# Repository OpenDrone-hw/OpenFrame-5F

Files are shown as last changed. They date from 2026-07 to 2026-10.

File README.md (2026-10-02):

# OpenFrame-5F

The 5" OpenFrame: a CNC carbon fibre freestyle FPV frame in the
incutec OpenDrone line. The 3" and 5" frames are separate repositories:
[OpenFrame-3F](https://github.com/OpenDrone-hw/OpenFrame-3F) and
[OpenFrame-5F](https://github.com/OpenDrone-hw/OpenFrame-5F).

<p>
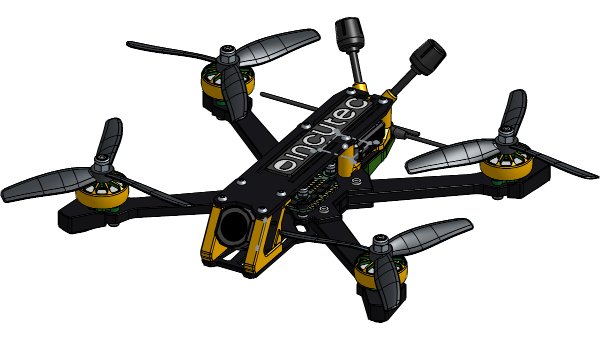
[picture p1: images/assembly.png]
OpenFrame-5F with electronics, Onshape assembly

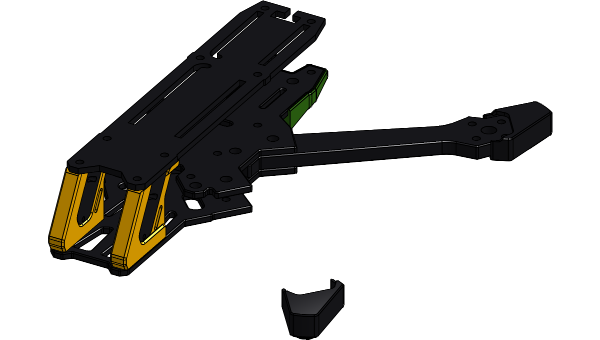
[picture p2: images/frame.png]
OpenFrame-5F frame parts, Onshape part studio

</p>



## Where the design lives

```mermaid
flowchart LR
  O["Onshape<br/>OpenDrone-V2, workspace 5 inch"] --> V["Named version"]
  V --> R["releases/rev/<br/>STEP, drawings, manifest"]
```

| | |
|---|---|
| Source | [Onshape document OpenDrone-V2, workspace 5"](https://cad.onshape.com/documents/78e093d02798373a79bc68d0/w/c0ca752de47c1227bb727503) |
| Link file | [`cad/onshape.json`](cad/onshape.json): document, workspace, element and part ids |
| Released exports | `releases/<rev>/`, exported from a named Onshape version and never edited. No revision has been released yet. |
| Parts per set | [`parts.csv`](parts.csv) |
| Fasteners and hardware | [`hardware.csv`](hardware.csv) |
| Standard | Incutec mechanical repository template |

## A set

15 part types, 23 pieces, 8 of them carbon. Taken from the
Onshape assembly; materials are as set in the Onshape model. The
Onshape material library has no TPU entry, so the TPU parts carry
`Polyurethane`; the pad carries `Silicone Rubber`.
VTX-Mount and anti-slip pad are taken from document versions `V4` and
`antislip pad v2` (`sourceVersion` in `cad/onshape.json`). A version cannot
be edited, so the model still gives VTX-Mount as PLA and the pad no material.

| Part | Qty | Material | Thickness | Made by |
|---|---|---|---|---|
| Arm | 4 | Carbon fiber epoxy (61%) | 6 mm | CNC carbon plate |
| Boot-L | 2 | Polyurethane |  | 3D print, TPU |
| Boot-R | 2 | Polyurethane |  | 3D print, TPU |
| Cam-Mount-L | 1 | Polyurethane |  | 3D print, TPU |
| Cam-Mount-R | 1 | Polyurethane |  | 3D print, TPU |
| Cross | 1 | Carbon fiber epoxy (61%) | 6 mm | CNC carbon plate |
| Airtag/Antenna mount | 1 | Polyurethane |  | 3D print, TPU |
| VTX-Mount | 1 | Polyurethane |  | 3D print, TPU |
| anti-slip pad | 1 | Silicone Rubber |  | moulded silicone |
| Base-Bot | 1 | Carbon fiber epoxy (61%) | 3 mm | CNC carbon plate |
| Base-Top | 1 | Carbon fiber epoxy (61%) | 3 mm | CNC carbon plate |
| Top | 1 | Carbon fiber epoxy (61%) | 2.5 mm | CNC carbon plate |
| 18mmx4mm | 4 | Aluminum |  | CNC aluminium |
| Standoff-L | 1 | Aluminum |  | CNC aluminium |
| Standoff-R | 1 | Aluminum |  | CNC aluminium |

Fasteners and hardware per set, from the same assembly:

| Item | Qty |
|---|---|
| Black-Oxide Alloy Steel Hex Drive Flat Head Screw | 5 |
| Hex socket head cap screw M3x0.50 x 8 | 16 |
| Prevailing torque nut M3x0.5 | 4 |
| Socket button head screw M3x0.5 x 12 | 4 |
| Socket button head screw M3x0.5 x 20 | 4 |
| Socket button head screw M3x0.5 x 6 | 8 |
| Socket button head screw M3x0.5 x 8 | 10 |
| m3 pressnut | 10 |
| softmount m2 | 8 |

The assembly's four M5 prop nuts belong to the motors and are left out of
`hardware.csv`; `cad/onshape.json` lists them under `modelCheck.ignoreHardware`.

## Model checks

Result of the Incutec Onshape model check, run on 2026-09-25 against a
branch of workspace 5" in the Onshape document. A row stays until the model is fixed.

| Check | Finding |
|---|---|
| Materials | `anti-slip pad` has no material set in the model |

## Key dimensions

| | 5" |
|---|---|
| Top plate | 2.5 mm |
| Middle plate | 3.0 mm |
| Bottom plate | 3.0 mm |
| Cross | 6.0 mm |
| Arm | 6.0 mm |
| Bolt holes | Ø3.1 (M3) |
| Press-nut holes | Ø4.5 (M3) |
| Bolt-head counterbore | Ø5.8 (M3 ISO 7380) |
| Countersink | none |
| Camera mount thread | M3 |

Chamfers 0.5 mm 45°, outer fillets R1.0 mm, inner fillets R1.05 mm unless the
released drawing says otherwise. The cross-to-arm interface is a press fit and is the
tightest tolerance in the design. These are design values: no drawings have been
released from this repository yet.

## Licence

Hardware licensed under [CERN-OHL-S-2.0](https://ohwr.org/cern_ohl_s_v2.txt),
see [LICENSE](LICENSE). Contributing: [CONTRIBUTING.md](CONTRIBUTING.md).

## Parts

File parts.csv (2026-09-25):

part | type | material | thickness_mm | qty_per_set | process | sku | onshape_part
Arm | arm | Carbon fiber epoxy (61%) | 6 | 4 | CNC carbon plate | ACC-FRM-ARM-5 | JHD
Boot-L | arm boot | Polyurethane |  | 2 | 3D print, TPU |  | RCBD
Boot-R | arm boot | Polyurethane |  | 2 | 3D print, TPU |  | RXBD
Cam-Mount-L | camera mount | Polyurethane |  | 1 | 3D print, TPU |  | RaBD
Cam-Mount-R | camera mount | Polyurethane |  | 1 | 3D print, TPU |  | RzBD
Cross | cross | Carbon fiber epoxy (61%) | 6 | 1 | CNC carbon plate | ACC-FRM-CROSS-5 | JHH
Airtag/Antenna mount | mount | Polyurethane |  | 1 | 3D print, TPU |  | ReBD
VTX-Mount | mount | Polyurethane |  | 1 | 3D print, TPU |  | REBH
anti-slip pad | pad | Silicone Rubber |  | 1 | moulded silicone |  | RLED
Base-Bot | plate | Carbon fiber epoxy (61%) | 3 | 1 | CNC carbon plate | ACC-FRM-BOT-5 | JND
Base-Top | plate | Carbon fiber epoxy (61%) | 3 | 1 | CNC carbon plate | ACC-FRM-MID-5 | JKD
Top | plate | Carbon fiber epoxy (61%) | 2.5 | 1 | CNC carbon plate | ACC-FRM-TOP-5 | JQD
18mmx4mm | standoff | Aluminum |  | 4 | CNC aluminium |  | J8D
Standoff-L | standoff | Aluminum |  | 1 | CNC aluminium |  | JpD
Standoff-R | standoff | Aluminum |  | 1 | CNC aluminium |  | J9D

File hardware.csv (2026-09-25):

item | standard | size | qty_per_set | notes
Black-Oxide Alloy Steel Hex Drive Flat Head Screw |  |  | 5 | from the Onshape assembly
Hex socket head cap screw M3x0.50 x 8 | ISO 4762 | M3x8 | 16 | from the Onshape assembly
Prevailing torque nut M3x0.5 |  | M3 | 4 | from the Onshape assembly
Socket button head screw M3x0.5 x 12 | ISO 7380 | M3x12 | 4 | from the Onshape assembly
Socket button head screw M3x0.5 x 20 | ISO 7380 | M3x20 | 4 | from the Onshape assembly
Socket button head screw M3x0.5 x 6 | ISO 7380 | M3x6 | 8 | from the Onshape assembly
Socket button head screw M3x0.5 x 8 | ISO 7380 | M3x8 | 10 | from the Onshape assembly
m3 pressnut |  |  | 10 | from the Onshape assembly
softmount m2 |  |  | 8 | from the Onshape assembly

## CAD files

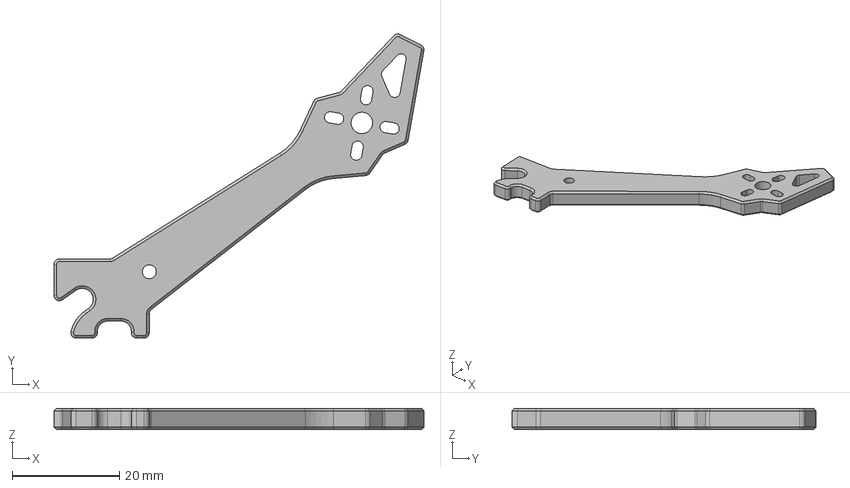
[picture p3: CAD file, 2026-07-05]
OpenFrame-3/OpenFrame-3_Arm.step.step
68.9 x 56.7 x 4.00 mm

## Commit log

2026-07-05 OpenFrame 3in and 5in: initial CAD export from Onshape
    [OpenFrame-3_Arm.step, OpenFrame-3_Bottom-plate.step, OpenFrame-3_Camera-mount-left.step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]
2026-07-06 Update design documentation
    [OpenFrame-3_Arm.step.step, OpenFrame-5_Arm.step, OpenFrame-5_Bottom-plate.step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]
2026-08-11 docs: ask contributors to raise proposals in Discord first
    CONTRIBUTING.md now points at the Discord server and asks contributors to tag
    the developers before opening an issue or starting work, so proposals get
    checked against work in progress, board locks and committed production runs.
2026-08-13 Reset to the planned shape: a specification, not a half-drawn design
    [OpenFrame-3_Arm.step, OpenFrame-3_Bottom-plate.step, OpenFrame-3_Camera-mount-left.step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]
2026-08-13 Reset to the planned shape: a specification, not a half-drawn design (#8)
    [OpenFrame-3_Arm.step, OpenFrame-3_Bottom-plate.step, OpenFrame-3_Camera-mount-left.step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]
2026-09-25 Set up OpenFrame-5F as a mechanical repository (#14)
    Follows the Incutec mechanical repository template: the Onshape source is
    linked from cad/onshape.json, parts.csv and hardware.csv list a set as the
    Onshape assembly has it, releases/ will hold the exports, and the README
    shows the model and its open checks.
    [hardware.csv, parts.csv]
2026-09-25 Release Cam-Mount-R with the 5-inch set (#15)
    The camera mounts are sold as a pair (ACC-FRM-CAM-5) and parts.csv counts
    both, but the right mount is missing from the 5-inch assembly, so the
    generated link file marked it not for release.
2026-09-25 Fix the README flowchart: an inch mark closed the label early (#16)
2026-09-25 Regenerate the model checks table from onshape_model_check.py (#17)
    The M5 prop nut exclusion moves into cad/onshape.json
    (modelCheck.ignoreHardware) and a note under the hardware table.
2026-09-25 Map the carbon plates to their SKUs and thicknesses (#18)
    Top, Base-Top and Base-Bot are the top, middle and bottom plates: measured
    thickness and stacking order in the Onshape Part Studio match the last
    released drawing.
    [parts.csv]
2026-09-25 Record TPU and silicone and the agent branch model checks (#19)
    Printed parts are TPU (library entry Polyurethane) and the pad is
    silicone (Silicone Rubber) in parts.csv and the README set table.
    cad/onshape.json names the Onshape branch agent/model-checks-5in under agentBranch.
    The Model checks table is regenerated with --agent-branch.
    [parts.csv]
2026-10-23 release: rev1 (2026-07-05 samples) and rev2 (2026-10-20 batch 1), changelog (#8)
    * release: rev1, the 2026-07-05 state the first CNC samples were cut from
    Onshape version 'OpenFrame-5F rev1', created from document history.
    * release: rev2, the 2026-10-20 state for the first production batch
    * docs: changelog per revision, hardware lists and README to rev2
    * docs: model review and hardware spec, screw roles in hardware.csv
    hardware.csv keeps the Onshape counts and names what each screw does: 6 holes
    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
2026-10-23 docs: rev3 and the Onshape fix branches in the changelog (#9)
    The model review table now says what is done on the Onshape fix branch and what
    is open. The 5 McMaster screws are part of the DJI O4 Pro reference model, not
    leftovers: corrected.
2026-10-24 release: rev2.2, final CNC parts and hardware (#10)
    * cad: follow the Onshape branch 5in-fixes (not merged in Onshape)
    The link file points its agentBranch at 5in-fixes (from version rev2).
    hardware.csv lists what the branch holds: the 11 imported screw bodies are now
    standard content (ISO 7380 M4x14 arms, M3x12 centre, 6 x M3x8), the stack is
    ISO 4762 M3x22, the 6 doubled M3x6 are gone, every standard screw class 12.9
    black. The imported screw part entries leave the link file.
    * cad: bottom side plate screws M3x8 on 5in-fixes (5 mm of thread in the 6 mm tap)
    * docs: fact-chec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
2026-10-24 README: assembled and exploded renders side by side (#11)
2026-10-24 releases/rev2.2: middle-plate nut holes for catalogue self-clinching nuts, camera-mount hole depths (#12)
    Exported from Onshape version OpenFrame-5F rev2.2 (workspace 5in-fixes).
    Base-Top: M3 4.22 + seat 6.7 x 1.55, M4 5.4 + seat 8.1 x 1.55. Standoff-L/R: tapped hole depths as set by the founder.
    All other parts geometrically identical to the earlier rev2.2 export; their files are kept.
2026-10-26 docs: bring README, CHANGELOG and bom.csv in line with the rev2.2 handoff package (#13)
    Self-clinching nuts, bolt hole tolerance +0.10/0, press fit, anti-slip pad rev B note, screw-length re-check marked open where ambiguous.
